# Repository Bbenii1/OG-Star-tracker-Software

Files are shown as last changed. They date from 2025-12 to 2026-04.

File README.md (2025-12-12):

<p align="center" style="height: 100px">
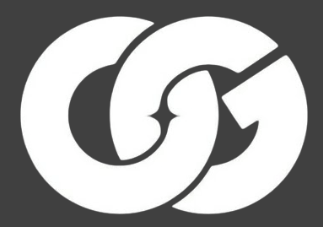
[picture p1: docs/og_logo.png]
  
</p>

> [!NOTE]  
> Fell free to try out my new hassle-free web based OG Star TrackerFirmware Flashing Tool by opening [this link](https://bbenii1.github.io/ogtracker-flash/).

# OG Star Tracker

OG Star Tracker is a mostly 3D printed star tracker which is cheaper than any competitor, but has the same features and can be controlled from it's self hosted web interface. It can be made as a diy project or you can [buy](https://ogstartech.com/shop/) it already assembled. The tracker can handle 400mm of focal length and up to 6kg of payload capacity if you upgrade to the heavy duty version. It is easily customizable and upgradable, for example you can add another axis to it, so you will be able to use it as a GO-TO tracker. The project is open source, therefore easy to make and contribute to. The project came true thanks to the founder [Ondrej Gejdos](https://github.com/OndraGejdos) and the amazing [community](https://discord.gg/Zj2jpAkn8b) that contributed to the project.

# What is this repository?

This is my restructured and simplified version of the [official repository](https://github.com/OG-star-tech/OG-star-tracker-). This repository only focuses on version 2 of the tracker, so if you would like to know more about version 1 of the tracker please go to the [official repository](https://github.com/OG-star-tech/OG-star-tracker-).

# How to build it?
There are a 3 options you can take when deciding how would you like to make the tracker.

### Preassembled kit
 If you like easy things and you don't want to fiddle with assembly then you can buy the [already assembled kit](https://ogstartech.com/product/og-star-tracker-v2-fully-build/) from the website.

### DIY kit
 You have the option to buy the [DIY kit](https://ogstartech.com/product/og-star-tracker-kit/) from the website with all of the parts included. You can easily assemble your tracker, the kit includes all of the parts that you will need. To your tracker assemble you can follow the included manual or the  [video guide](https://www.youtube.com/watch?v=8lNT1Yxl7aw).

### DIY on your own

You might have a 3D printer and you would like to print the parts for the tracker? Then do so! You can find the [3D files](https://www.printables.com/model/348574-og-star-tracker-v2) on Printables and download them from there. To assemble the tracker you will also need some additional parts. For those you can buy the [hardware kit](https://ogstartech.com/product/og-star-tracker-hw-kit/) that includes all the needed parts apart from the 3D printed ones, or you can buy them separately on your own using [the list of parts](ttps://docs.google.com/spreadsheets/d/1V04zjGSebJ5LQbSmzs-h86T6Z9E3HwVkMj2nuVYQzYs/edit?gid=0#gid=0) or the list below. To your tracker assemble you can follow the [video guide](https://www.youtube.com/watch?v=8lNT1Yxl7aw).

> [!WARNING]  
> If you buy the parts on your own separately, you will need the [V2 PCB](https://ogstartech.com/product/og-star-tracker-pcb-board/) to be able to use the tracker.

<details>
<summary>Parts for assembly</summary>

|Parts | Quantity |
|---|---|
| M3x6 socket bolt | 2 |
| M3x8 socket bolt | 40 |
| M3x16 socket bolt | 4 |
| M3x20 socket bolt | 8 |
| M3x40 socket bolt | 4 |
| M5x20 Low profile socket bolt  | 1 |
| M5x25 socket bolt | 1 |
| M5x50 Hex head | 2 |
| M5 ptfe washer | 1 |
| M3 threaded insert | 60 |
| M5 threaded insert | 5 |
| M3 nut | 3 |
| M5 nut | 3 |
| M5 self-tightening nuts | 2 |
| ¼-20x1/2” UNC Hex head | 2 |
| 3/8-16 threaded insert | 1 |
| ¼-20 UNC to 3/8-20 UNC adapter | 2 |
| AXK 5070 needle bearing | 2 |
| AS 5070 Axial bearing washer | 4 |
| KU 5025 sleeve bearing | 1 |
| 625 bearing | 10 |
| GT2 16 teeth pulley | 3 |
| GT2 48 teeth pulley | 2 |
| GT2 20 teeth idler | 1 |
| GT2 120mm belt | 2 |
| GT2 400mm belt | 1 |
| 5x50mm shaft | 2 |
| M5x95mm rod | 1 |
| M5x135mm rod | 1 |
| Round bubble level 12x7mm | 1 |
| PTFE based grease | 1 |
| Round magnet 10x3mm | 4 |
| Round magnet 5x5mm | 2 |
| Stepper motor | 1 |
| [PCB](https://ogstartech.com/product/og-star-tracker-pcb-board/) | 1 |

|Optional parts|
|-|
| Glue                           |     1    |
| Laser or polar scope           |
| 4mm hex key                    |
| 2.5mm hex key                  |
| 2mm hex key                    |
</details>

<br>

# Features
- Wirelessly Control the tracker from your phone/laptop by connecting to a webpage
- Supports AP (Access Point) and STA (Station) mode
 -- AP  : The ESP32 will create a wifi network which you can connect to
 -- STA : The ESP32 connects to an existing wifi network specified by you, Ex: phone hotspot. (Not fully tested)
- Integrated intervalometer which can control your camera shutter, no need to buy extra hardware. Exposures can be controlled via the webpage
  - Intervalometer Modes:
    - Long Exposure Still: Classic astro mode with tracking to get long exposures on the same target. Optional dithering.
    - Long Exposure Movie: Long exposures with tracking and dither plus at the end of a set of exposures the axis is rewound (a frame) and the next set started. This give the ability to create a movie          of the night sky moving over a terrestrial object when couple with a video making software.
    -  Day Time Lapse: Standard time lapse with exposure settings controlled by the camera.
    -  Day Time Lapse with Pan: Standard time lapse with exposure settings controlled by the camera plus a pan of X degrees in between every exposure.
- Presets : Up to 10 preset intervalometer settings can be saved for retrieval next session.
- Slewing supported at different speeds.

# Important links

Website - [ogstartech.com](https://ogstartech.com/) <br>
Discord - [Community](https://discord.gg/Zj2jpAkn8b) <br>
Printables - [printables.com](https://www.printables.com/model/348574-og-star-tracker-v2)

## License

This work is licensed under a
[Creative Commons Attribution-NonCommercial-ShareAlike 4.0 International License](http://creativecommons.org/licenses/by-nc-sa/4.0/)



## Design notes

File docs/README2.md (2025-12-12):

# OG Star Tracker : Wireless Control Hardware (Rev 2.0)

This simple PCB and firmware intends to make it easier to control the OG Star Tracker. If you have any suggestions/ideas about new features or would like to contribute, post in the OG star tracker [discord server](https://discord.com/invite/dyFKm79gKJ) or message me (Discord: jahh#8924).
If you like this work, feel free to connect with me on [Github](https://github.com/jugal2001) or [Linkedin](https://www.linkedin.com/in/jugaljesing/).

## Table of Contents
- [Compiling](compiling.md)
- [Wifi Config](wifi_config.md)

## Firmware

The firmware for the PCB is provided in this repository and can be compiled and flashed with the given [instructions](compiling.md).
Upon turning on the tracker will create an access point with the following default credentials that you can use to connect and control it:

```
SSID: OG Star Tracker
Password: password123
```

After a successful connection you can open **tracker.local** in your browser using your phone or desktop. The tracker hosts its own interface for convenient controlling.

You can set your own wifi configuration following [this tutorial](wifi_config.md).

[API](API.md)

## App

If the webserver is not enough there is a app available to improve the accessibility even further.
Check out https://github.com/OndraGejdos/OG-star-tracker-App for more details.

## Contributing

When contributing to the project please make sure to follow the [coding style](docs/coding-style.md) prior creating a pull request.
With this we can make sure to keep a clean and tidy codespace.

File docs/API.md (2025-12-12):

# OG Star Tracker REST API Documentation

## Overview
The OG Star Tracker provides a REST API over HTTP for remote control and monitoring. All endpoints use GET requests and return either plain text or JSON responses.

**Base URL:** `http://<device-ip>/`  
**Default Port:** 80

---

## Table of Contents
1. [Tracking Control](#tracking-control)
2. [Slewing Control](#slewing-control)
3. [Goto Control](#goto-control)
4. [Position Management](#position-management)
5. [Intervalometer Control](#intervalometer-control)
6. [Tracking Rates](#tracking-rates)
7. [Status & Info](#status--info)
8. [Catalog Search](#catalog-search)
9. [Settings](#settings)
10. [OTA Firmware Update](#ota-firmware-update)

---

## Tracking Control

### Enable Tracking
**Endpoint:** `GET /on`  
**Description:** Enable sidereal tracking at specified rate and direction

**Parameters:**
| Parameter | Type | Required | Description |
|---|---|---|---|
| `direction` | integer | Yes | Hemisphere/direction: 0=northern/clockwise, 1=southern/counter-clockwise |
| `trackingSpeed` | integer | Yes | Tracking rate value (depends on tracking rate type selected) |

**Response:** `200 OK` - "Tracking ON"

**Example:**
```
GET http://192.168.4.1/on?direction=0&trackingSpeed=15956
```

### Disable Tracking
**Endpoint:** `GET /off`  
**Description:** Disable sidereal tracking  
**Response:** `200 OK` - "Tracking OFF"

**Example:**
```
GET http://192.168.4.1/off
```

---

## Slewing Control

### Start Slewing
**Endpoint:** `GET /startslew`  
**Description:** Start manual slewing at specified speed  

**Parameters:**
| Parameter | Type | Required | Description |
|---|---|---|---|
| `speed` | integer | Yes | Slew speed multiplier (2-400, lower=faster) |
| `direction` | integer | Yes | Direction: 0=left/west, 1=right/east |

**Response:** `200 OK` - "Slewing"

**Example:**
```
GET http://192.168.4.1/startslew?speed=16&direction=1
```

### Stop Slewing
**Endpoint:** `GET /stopslew`  
**Description:** Stop current slewing operation  
**Response:** `200 OK` - "Slew Cancelled"

**Example:**
```
GET http://192.168.4.1/stopslew
```

---

## Goto Control

### Goto RA Position
**Endpoint:** `GET /gotoRA`  
**Description:** Move mount to target RA position  

**Parameters:**
| Parameter | Type | Required | Description |
|---|---|---|---|
| `currentRA` | string | Yes | Current RA position (HH:MM:SS format) |
| `targetRA` | string | Yes | Target RA position (HH:MM:SS format) |
| `speed` | integer | Yes | Goto speed multiplier (2-400, lower=faster) |

**Response:** `200 OK` - "Goto RA - Panning ON"

**Example:**
```
GET http://192.168.4.1/gotoRA?currentRA=12:30:45&targetRA=14:20:30&speed=8
```

### Abort Goto
**Endpoint:** `GET /abort-goto-ra`  
**Description:** Abort current goto RA operation  
**Response:** `200 OK` - "Goto RA aborted"

**Example:**
```
GET http://192.168.4.1/abort-goto-ra
```

---

## Position Management

### Set Position
**Endpoint:** `GET /setPosition`  
**Description:** Set current mount position  

**Parameters:**
| Parameter | Type | Required | Description |
|---|---|---|---|
| `currentRA` | string | Yes | Current RA position (HH:MM:SS format) |

**Response:** `200 OK` - "Position Set Success"

**Example:**
```
GET http://192.168.4.1/setPosition?currentRA=12:30:45
```

### Get Current Position
**Endpoint:** `GET /getCurrentPosition`  
**Description:** Get current mount position in steps  

**Response:** `200 OK` - JSON object
```json
{
  "position": 123456
}
```

**Example:**
```
GET http://192.168.4.1/getCurrentPosition
```

---

## Intervalometer Control

### Configure and Start Capture
**Endpoint:** `GET /setCurrent`  
**Description:** Configure and start intervalometer capture sequence  

**Parameters:**
| Parameter | Type | Required | Description |
|---|---|---|---|
| `mode` | integer | Yes | 0=start capture, 1=save to preset |
| `preset` | integer | Yes | Preset number (0-4) |
| `captureMode` | integer | Yes | 0=LONG_EXPOSURE_STILL, 1=LONG_EXPOSURE_MOVIE, 2=TIMELAPSE, 3=TIMELAPSE_PAN, |
| `exposureTime` | integer | Yes | Exposure duration in seconds |
| `exposures` | integer | Yes | Number of exposures |
| `preDelay` | integer | Yes | Pre-delay in seconds |
| `delay` | integer | Yes | Delay between exposures in seconds |
| `frames` | integer | Yes | Number of frames (for MOVIE mode) |
| `panAngle` | integer | Yes | Pan angle in degrees × 100 |
| `panDirection` | integer | Yes | 0=left/west, 1=right/east |
| `enableTracking` | integer | Yes | 0=off, 1=on |
| `ditherChoice` | integer | Yes | 0=off, 1=on |
| `ditherFrequency` | integer | Yes | Dither every N exposures |
| `focalLength` | integer | Yes | Focal length in mm |
| `pixelSize` | integer | Yes | Pixel size in microns × 100 |

**Response:** `200 OK` - Success message or error

**Example:**
```
GET http://192.168.4.1/setCurrent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
```

### Read Preset
**Endpoint:** `GET /readPreset`  
**Description:** Load intervalometer preset settings  

**Parameters:**
| Parameter | Type | Required | Description |
|---|---|---|---|
| `preset` | integer | Yes | Preset number (0-4) |

**Response:** `200 OK` - JSON object with preset settings
```json
{
  "mode": 0,
  "exposures": 10,
  "delay": 2,
  "preDelay": 5,
  "exposureTime": 30,
  "panAngle": 0,
  "panDirection": 1,
  "ditherChoice": 1,
  "ditherFrequency": 3,
  "enableTracking": 1,
  "frames": 1,
  "pixelSize": 350,
  "focalLength": 200
}
```

**Example:**
```
GET http://192.168.4.1/readPreset?preset=0
```

### Abort Capture
**Endpoint:** `GET /abort`  
**Description:** Abort current intervalometer capture sequence  
**Response:** `200 OK` - "Capture OFF"

**Example:**
```
GET http://192.168.4.1/abort
```

---

## Tracking Rates

### Get Tracking Rates
**Endpoint:** `GET /getTrackingRates`  
**Description:** Get current tracking rate configuration  

**Response:** `200 OK` - JSON object
```json
{
  "type": 0,
  "customRate": 0
}
```
**Types:** 0=SIDEREAL, 1=LUNAR, 2=SOLAR, 3=CUSTOM

**Example:**
```
GET http://192.168.4.1/getTrackingRates
```

### Save Tracking Rate Preset
**Endpoint:** `GET /saveTrackingRatePreset`  
**Description:** Save tracking rate to preset  

**Parameters:**
| Parameter | Type | Required | Description |
|---|---|---|---|
| `preset` | integer | Yes | Preset number (0-4) |
| `type` | integer | Yes | 0=SIDEREAL, 1=LUNAR, 2=SOLAR, 3=CUSTOM |
| `customRate` | integer | No | Custom rate value (required if type=3) |

**Response:** `200 OK` - Success message

**Example:**
```
GET http://192.168.4.1/saveTrackingRatePreset?preset=0&type=0&customRate=0
```

### Load Tracking Rate Preset
**Endpoint:** `GET /loadTrackingRatePreset`  
**Description:** Load tracking rate from preset  

**Parameters:**
| Parameter | Type | Required | Description |
|---|---|---|---|
| `preset` | integer | Yes | Preset number (0-4) |

**Response:** `200 OK` - JSON object with tracking rate settings

**Example:**
```
GET http://192.168.4.1/loadTrackingRatePreset?preset=0
```

---

## Status & Info

### Get Status
**Endpoint:** `GET /status`  
**Description:** Get device status information  

**Response:** `200 OK` - JSON object
```json
{
  "slewActive": false,
  "trackingActive": true,
  "intervalometerActive": false,
  "goToTarget": false,
  "exposuresTaken": 0,
  "currentExposure": 0
}
```

**Example:**
```
GET http://192.168.4.1/status
```

### Get Version
**Endpoint:** `GET /version`  
**Description:** Get firmware version and build information  

**Response:** `200 OK` - JSON object
```json
{
  "version": "v2.1",
  "buildDate": "Nov 22 2025 10:30:00",
  "internalVersion": 210
}
```

**Response Fields:**
| Field | Type | Description |
|---|---|---|
| `version` | string | Firmware version string (from BUILD_VERSION define) |
| `buildDate` | string | Compilation date and time |
| `internalVersion` | integer | Internal version number for comparison |

**Example:**
```
GET http://192.168.4.1/version
```

**Notes:**
- `buildDate` format: "MMM DD YYYY HH:MM:SS" (e.g., "Nov 22 2025 10:30:00")
- `internalVersion` is a numeric value for programmatic version comparison
- Same data returned by `/checkversion` endpoint in OTA section

---

## Catalog Search

### Search Star/Object Catalog
**Endpoint:** `GET /starSearch`  
**Description:** Search star/object catalog by name  

**Parameters:**
| Parameter | Type | Required | Description |
|---|---|---|---|
| `catalog` | integer | Yes | 0=NGC2000, 1=NGC2000_COMPACT, 2=BSC5, 3=BSC5_COMPACT |
| `query` | string | Yes | Search query string (star/object name) |

**Response:** `200 OK` - JSON object with search results

**Example:**
```
GET http://192.168.4.1/starSearch?catalog=0&query=M31
```

---

## Settings

### Set Language
**Endpoint:** `GET /setlang`  
**Description:** Set web interface language  

**Parameters:**
| Parameter | Type | Required | Description |
|---|---|---|---|
| `lang` | integer | Yes | 0=English, 1=German, 2=Chinese |

**Response:** `200 OK` - Success message

**Example:**
```
GET http://192.168.4.1/setlang?lang=0
```

### Get Current Language
**Endpoint:** `GET /getlang`
**Description:** Get currently selected language index

**Response:** `200 OK` - JSON object
```json
{
  "lang": 0
}
```

**Example:**
```
GET http://192.168.4.1/getlang
```

### Get Language Strings
**Endpoint:** `GET /langstrings`
**Description:** Get all translated strings for current language as JSON

**Response:** `200 OK` - JSON object with language strings and language names
```json
{
  "strings": {
    "%STR_TRACKING%": "Tracking",
    "%STR_SLEWING%": "Slewing",
    ...
  },
  "langNames": ["English", "Deutsch", "中文"]
}
```

**Example:**
```
GET http://192.168.4.1/langstrings
```

**Notes:**
- Response is streamed using chunked encoding to reduce memory usage
- Contains all UI string placeholders and their translations
- Language names array used for building language selector dropdown

### Get Web Interface
**Endpoint:** `GET /`  
**Description:** Serve main web interface HTML  

**Response:** `200 OK` - HTML content

**Example:**
```
GET http://192.168.4.1/
```

---

## OTA Firmware Update

### Get OTA Update Page
**Endpoint:** `GET /ota`  
**Description:** Serve OTA firmware update web interface  

**Response:** `200 OK` - HTML content with firmware update interface

**Example:**
```
GET http://192.168.4.1/ota
```

---

### Check for Updates
**Endpoint:** `GET /checkversion`  
**Description:** Check GitHub for latest firmware release and compare with current version  

**Response:** `200 OK` - JSON object
```json
{
  "currentVersion": "v2.1",
  "buildDate": "Nov 22 2025 10:30:00",
  "latestVersion": "v2.1-beta03",
  "releaseUrl": "https://github.com/OG-star-tech/OG-star-tracker-/releases/tag/v2.1-beta03",
  "downloadUrl": "https://github.com/OG-star-tech/OG-star-tracker-/releases/download/v2.1-beta03/firmware.bin",
  "releaseNotes": "Bug fixes|Performance improvements|New features"
}
```

**Error Response:**
```json
{
  "currentVersion": "v2.1",
  "buildDate": "Nov 22 2025 10:30:00",
  "error": "No internet connection. If in AP mode, connect device to WiFi network with internet access."
}
```

**Example:**
```
GET http://192.168.4.1/checkversion
```

**Notes:**
- **Requires internet access:** Device must be connected to a WiFi network with internet access (not AP mode)
- **AP Mode Limitation:** When device is in Access Point mode, it cannot reach GitHub API. Connect the device to a WiFi network with internet access first
- Release notes are pipe-separated (|) for multi-line display
- Returns latest release even if same or older than current version

---

### Download and Install Update
**Endpoint:** `GET /downloadupdate`  
**Description:** Download firmware from URL and install automatically (GitHub release or custom URL)  

**Parameters:**
| Parameter | Type | Required | Description |
|---|---|---|---|
| `url` | string | Yes | Direct URL to firmware.bin file (URL-encoded) |

**Response:** `200 OK` - "Starting download..."

**Example:**
```
GET http://192.168.4.1/downloadupdate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
```

**Process Flow:**
1. Server validates URL parameter and WiFi connection
2. Returns immediate response "Starting download..."
3. Downloads firmware in background (512-byte chunks)
4. Writes to flash partition with verification
5. Device reboots automatically after 6 seconds if successful

**Error Responses:**
- `400 Bad Request` - "Missing URL parameter"
- `500 Internal Server Error` - "WiFi not connected"

**Notes:**
- **Requires internet access:** Device must be connected to a WiFi network with internet access (not AP mode)
- Use `/otastatus` endpoint to monitor download progress
- Device stays responsive during download (polls every 500ms)
- Typical download time: 30-60 seconds for ~1.2MB firmware
- URL must point directly to `.bin` file

---

### Manual Firmware Upload
**Endpoint:** `POST /update`  
**Description:** Upload firmware binary file directly via HTTP POST (multipart/form-data)  

**Content-Type:** `multipart/form-data`

**Form Field:**
| Field | Type | Description |
|---|---|---|
| `firmware` | file | Binary firmware file (.bin format) |

**Response:** `200 OK` - "Update Success! Rebooting..." or "Update Failed"

**Example (curl):**
```bash
curl -X POST -F "firmware=@firmware.bin" http://192.168.4.1/update
```

**Process Flow:**
1. Receives firmware chunks via multipart upload
2. Writes directly to flash partition during upload
3. Verifies integrity after upload completes
4. Device reboots automatically after 6 seconds if successful

**Notes:**
- Maximum file size: Limited by available flash partition (~2MB typical)
- Upload progress reported via `/otastatus` endpoint
- Use `/complete` endpoint to trigger reboot after upload verification

---

### Get OTA Status
**Endpoint:** `GET /otastatus`  
**Description:** Get real-time status of ongoing OTA update (upload or download)  

**Response:** `200 OK` - JSON object
```json
{
  "active": true,
  "complete": false,
  "error": false,
  "bytesWritten": 524288,
  "totalBytes": 1244160,
  "percent": 42
}
```

**Status Fields:**
| Field | Type | Description |
|---|---|---|
| `active` | boolean | Update is actively downloading/uploading |
| `complete` | boolean | Update completed successfully, ready to reboot |
| `error` | boolean | Update failed (check serial output for details) |
| `bytesWritten` | integer | Bytes written to flash so far |
| `totalBytes` | integer | Total firmware size in bytes |
| `percent` | integer | Progress percentage (0-100) |

**Example:**
```
GET http://192.168.4.1/otastatus
```

**Polling Pattern:**
```javascript
// Poll every 500ms during update
const interval = setInterval(async () => {
  const response = await fetch('/otastatus');
  const data = await response.json();
  
  if (data.active) {
    console.log(`Progress: ${data.percent}%`);
  } else if (data.complete) {
    console.log('Update complete, device rebooting...');
    clearInterval(interval);
  } else if (data.error) {
    console.log('Update failed');
    clearInterval(interval);
  }
}, 500);
```

**Notes:**
- Poll during `/downloadupdate` or `/update` operations
- `active=false, complete=false, error=false` at 100% indicates verification phase
- Verification timeout: 5 seconds (frontend should show error after timeout)

---

### Complete OTA Update
**Endpoint:** `GET /complete`  
**Description:** Finalize OTA update and trigger device reboot (called automatically by frontend)  

**Response:** `200 OK` - "Update Success! Rebooting..." or "Update Failed"

**Example:**
```
GET http://192.168.4.1/complete
```

**Notes:**
- Checks for errors before rebooting
- 6-second delay before reboot (server stays responsive)
- Typically called automatically by OTA web interface
- Returns error status if update verification failed

---

### OTA Update Workflow

**Automatic Update (GitHub):**
```
1. GET /checkversion                    -> Get latest release info
2. User confirms update
3. GET /downloadupdate?url=<firmware>   -> Start download
4. Poll GET /otastatus every 500ms      -> Monitor progress (0-100%)
5. Verification phase (2-5 seconds)     -> active=false, complete waiting
6. GET /complete called automatically   -> Trigger reboot
7. Device reboots after 6 seconds
```

**Manual Upload:**
```
1. User selects .bin file
2. POST /update with multipart form     -> Upload begins
3. Poll GET /otastatus every 500ms      -> Monitor progress (0-100%)
4. Verification phase (2-5 seconds)     -> active=false, complete waiting
5. GET /complete called automatically   -> Trigger reboot
6. Device reboots after 6 seconds
```

**Error Handling:**
- Flash read failures detected during verification
- Timeout if verification exceeds 5 seconds
- Write errors reported immediately via `/otastatus` (error=true)
- Serial output provides detailed error messages

**Safety Features:**
- Server remains responsive during entire process (non-blocking delays)
- Progress tracking prevents UI from hanging
- Automatic rollback on write failures
- 6-second countdown gives user time to see status

---

## Error Responses

All endpoints may return error messages in plain text format with appropriate HTTP status codes:

- `400 Bad Request` - Invalid parameters
- `404 Not Found` - Endpoint not found
- `500 Internal Server Error` - Server error

---

## Notes

1. **RA Format:** All RA positions use HH:MM:SS format (e.g., "12:30:45")
2. **Scaled Values:** Some values are scaled by 100 (panAngle, pixelSize) to avoid floating point in URL parameters
3. **Direction Convention:** 0=left/west, 1=right/east for all directional parameters
4. **Speed Convention:** Lower speed values = faster movement (range: 2-400)
5. **Preset Numbering:** All presets are numbered 0-4 (5 presets total)

---

## Example Usage

### Python Example
```python
import requests

# Base URL of your star tracker
base_url = "http://192.168.4.1"

# Enable tracking
response = requests.get(f"{base_url}/on")
print(response.text)

# Start a 30-second exposure timelapse with 10 exposures
params = {
    "mode": 0,
    "preset": 0,
    "captureMode": 0,
    "exposureTime": 30,
    "exposures": 10,
    "preDelay": 5,
    "delay": 2,
    "frames": 1,
    "panAngle": 0,
    "panDirection": 1,
    "enableTracking": 1,
    "ditherChoice": 0,
    "ditherFrequency": 1,
    "focalLength": 200,
    "pixelSize": 350
}
response = requests.get(f"{base_url}/setCurrent", params=params)
print(response.text)

# Check status
response = requests.get(f"{base_url}/status")
print(response.json())
```

### JavaScript Example
```javascript
const baseUrl = "http://192.168.4.1";

// Enable tracking
fetch(`${baseUrl}/on`)
  .then(response => response.text())
  .then(data => console.log(data));

// Get status
fetch(`${baseUrl}/status`)
  .then(response => response.json())
  .then(data => console.log(data));

// Start slewing
fetch(`${baseUrl}/startslew?speed=16&direction=1`)
  .then(response => response.text())
  .then(data => console.log(data));
```

---

## Version History

- **v2.1.0-beta03** - Initial REST API documentation
  - Added TIMELAPSE_PAN mode
  - Improved position tracking
  - Enhanced error handling
  - Added OTA firmware update endpoints
  - Real-time update progress tracking
  - Automatic and manual update support

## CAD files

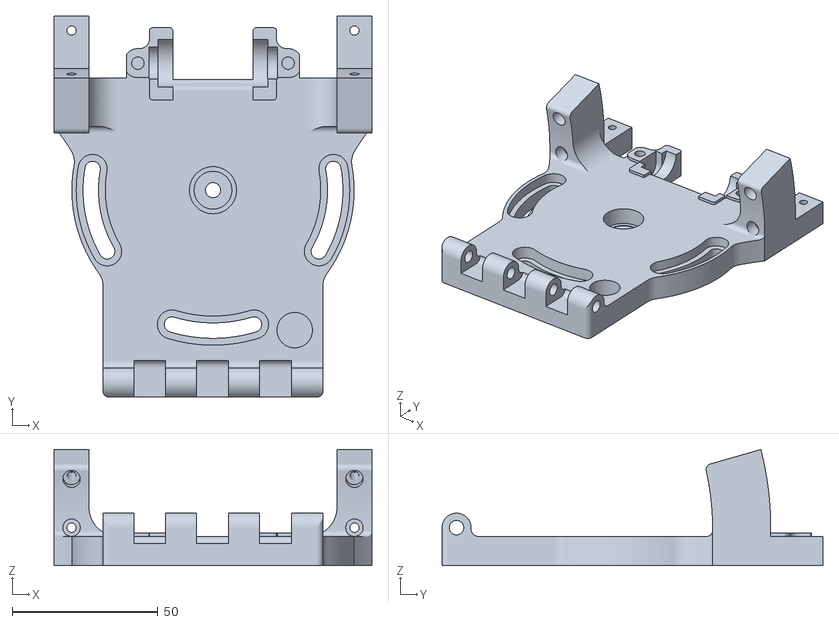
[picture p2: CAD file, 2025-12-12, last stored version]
mechanics/Heavy duty/main-bottom-part-hd.stl
109.2 x 130.9 x 39.9

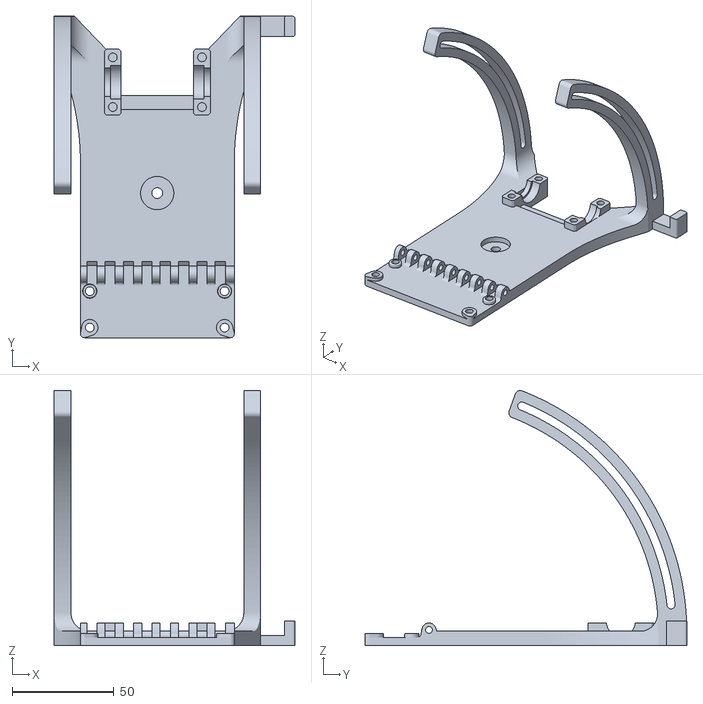
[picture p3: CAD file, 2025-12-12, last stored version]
v1/mechanics/bottom asembly/bottom main part.stl
118.2 x 157.9 x 125.2

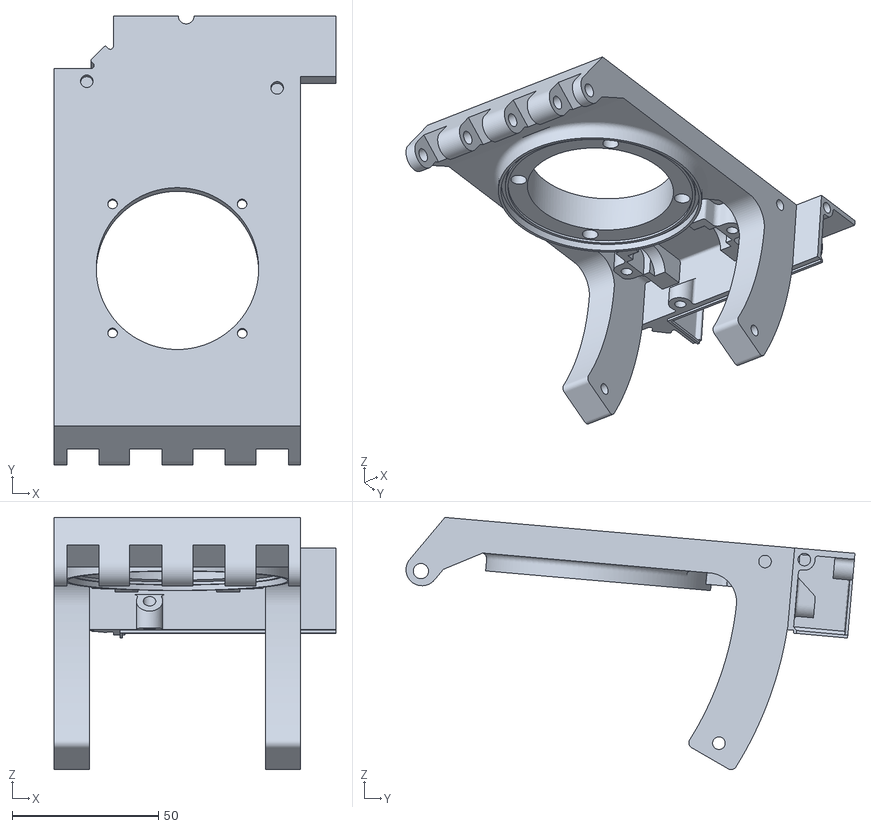
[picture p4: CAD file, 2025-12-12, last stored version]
mechanics/Heavy duty/main-top-part-hd.stl
96.2 x 153.4 x 86.2

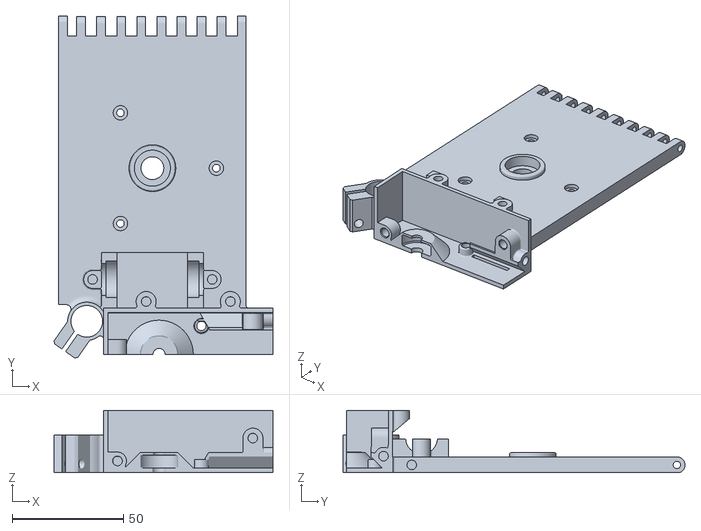
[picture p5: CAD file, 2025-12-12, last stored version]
v1/mechanics/top asembly/main part.stl
98.2 x 153.5 x 28.0

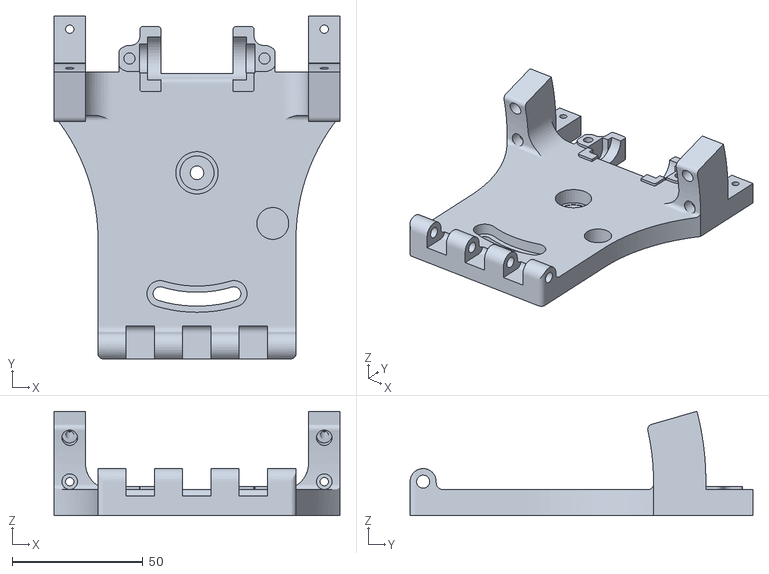
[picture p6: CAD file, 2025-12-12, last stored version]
mechanics/V2 files/main-bottom-part.stl
109.2 x 130.9 x 39.9

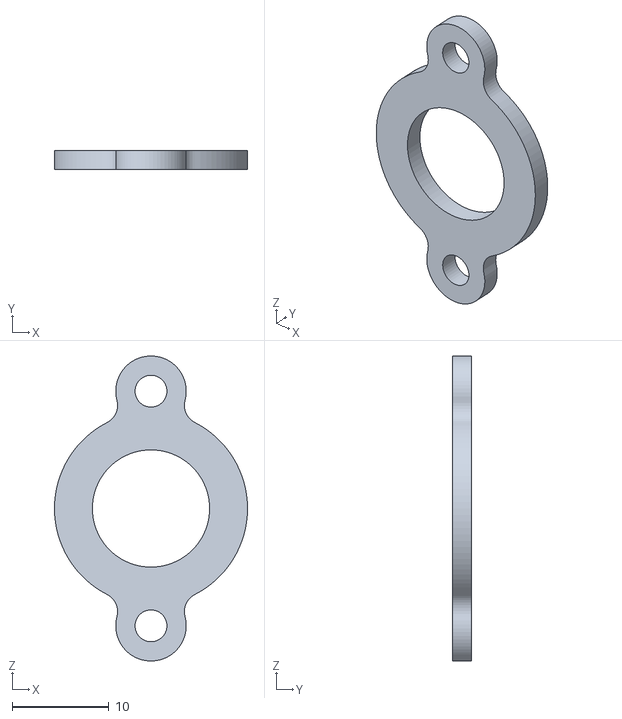
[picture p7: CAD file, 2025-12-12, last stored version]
mechanics/V2 files/main-gearbox-bearing-holderstl.stl
20.0 x 2.00 x 31.6

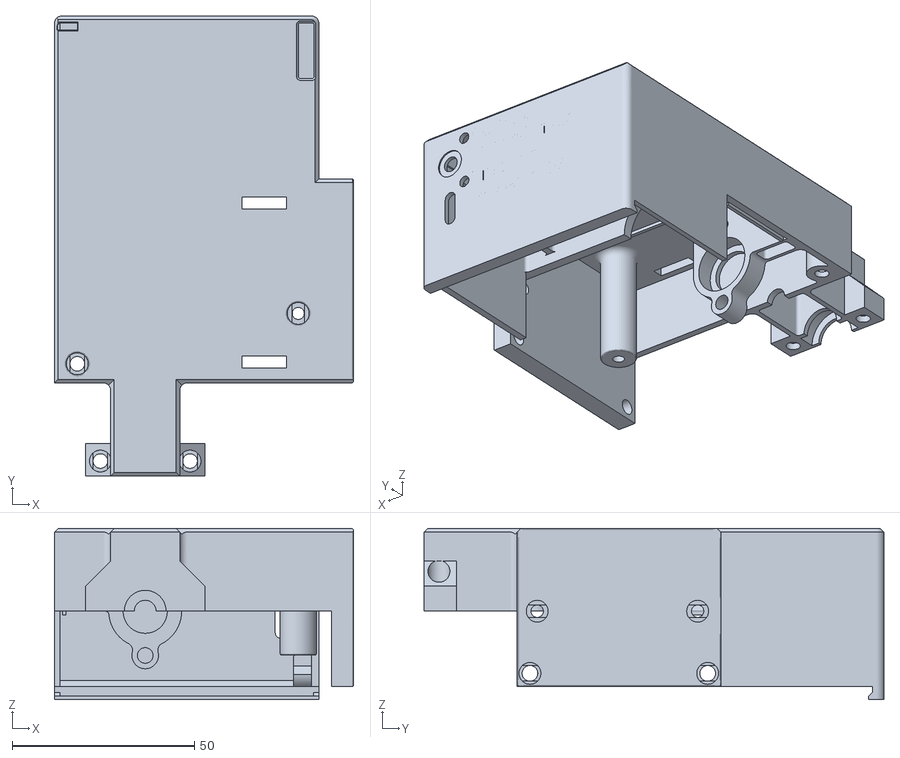
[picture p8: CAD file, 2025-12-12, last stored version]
mechanics/V2 files/main-gearbox.stl
82.0 x 126.2 x 47.0

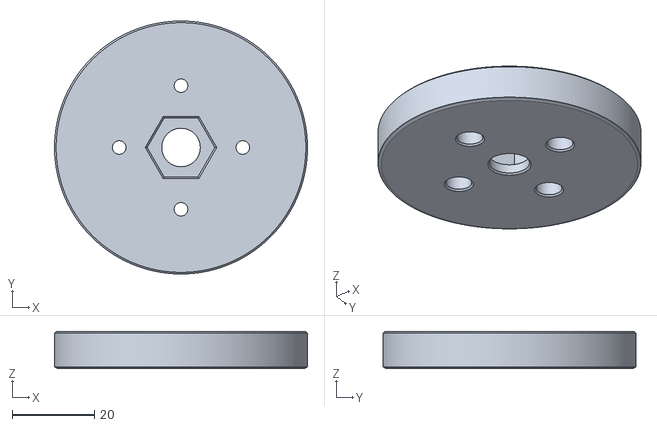
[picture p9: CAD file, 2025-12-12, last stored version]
community_upgrades/beefier_gearbox_multicolor/stls/camera-holder-3-8-16-x-1-2.stl
61.4 x 61.4 x 9.00

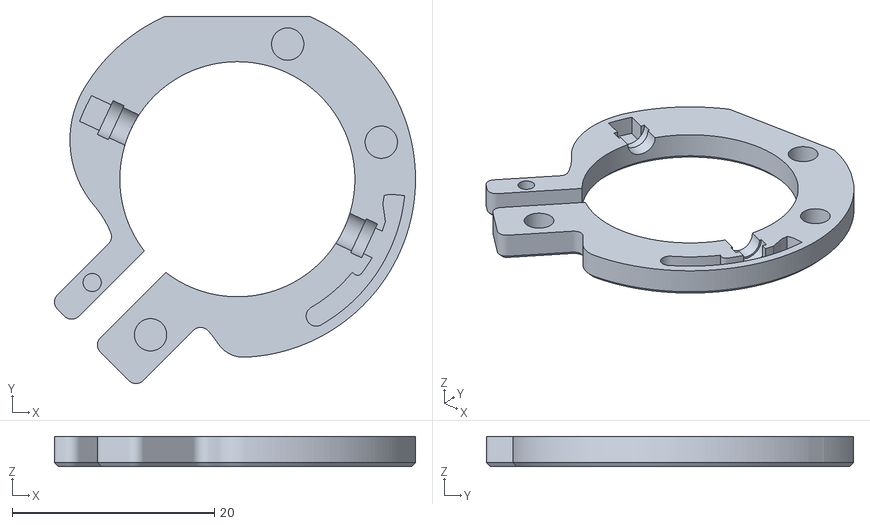
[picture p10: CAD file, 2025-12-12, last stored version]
community_upgrades/illuminated_polarscope/stls/led-top-cap.stl
35.7 x 36.3 x 3.00

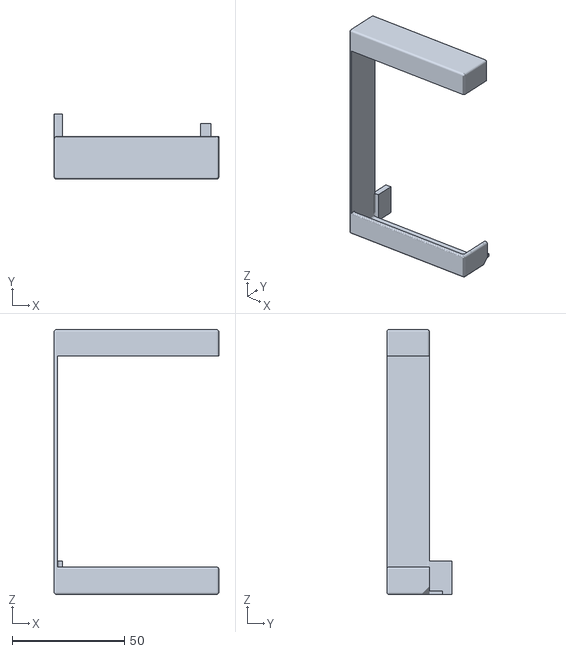
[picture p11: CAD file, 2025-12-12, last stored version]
community_upgrades/power_bank_holder/OGstartracker ONN battery mount.stl
73.4 x 29.2 x 118.2

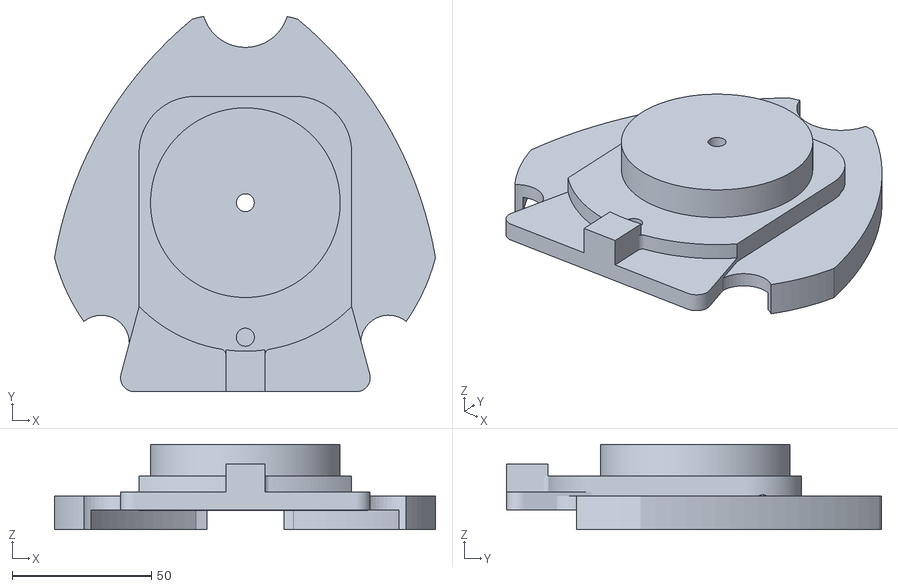
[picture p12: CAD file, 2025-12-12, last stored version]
community_upgrades/surveyor_tripod_adapter/stationary_part_with_surveyor_adapter2.stl
136.6 x 134.6 x 30.6

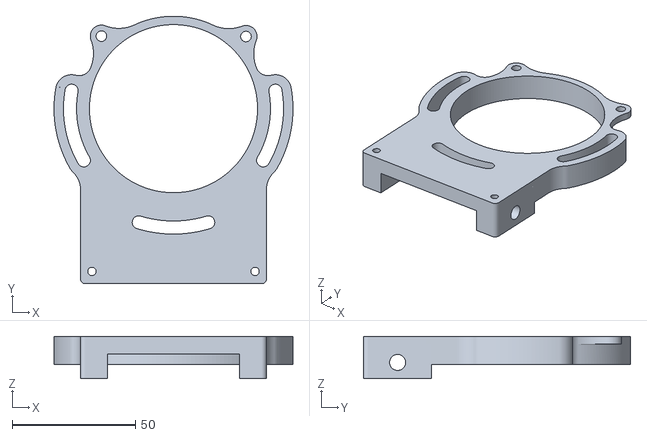
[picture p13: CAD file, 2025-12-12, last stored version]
mechanics/Heavy duty/middle-part-hd.stl
97.0 x 108.6 x 17.1

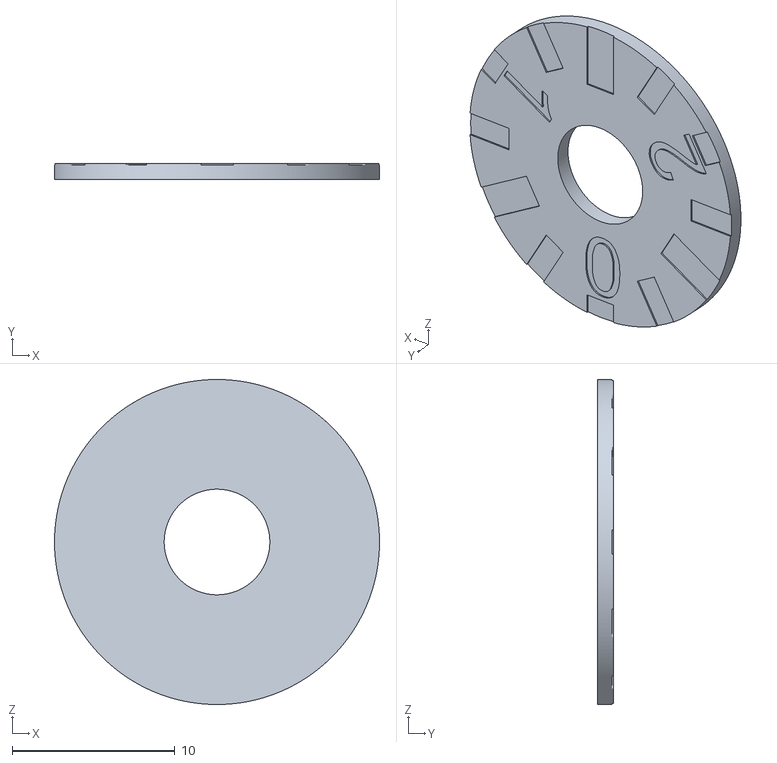
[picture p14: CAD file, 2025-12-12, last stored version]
mechanics/Manual go-to beta testing/small-scale-2.stl
20.0 x 1.00 x 20.0

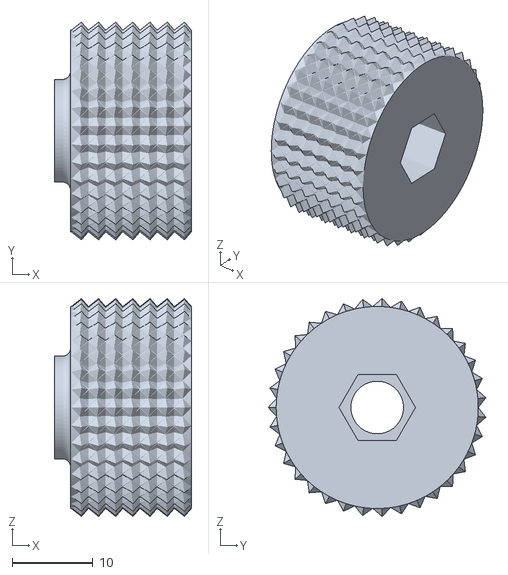
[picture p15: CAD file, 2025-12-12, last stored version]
mechanics/V2 files/m5-knob.stl
17.0 x 26.9 x 27.0

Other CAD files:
mechanics/V2 files/main-top-part.stl
v1/mechanics/electronic box/top cover.stl
v1/mechanics/top asembly/tightener 2x.stl
v1/mechanics/you also need to print this/bottom holder 2x!.stl
community_upgrades/beefier_gearbox_multicolor/stls/belt-cover-modded-needs_supports.stl
community_upgrades/beefier_gearbox_multicolor/stls/belt-tightener-625-bearing-m5x16mm.stl
community_upgrades/beefier_gearbox_multicolor/stls/belt-tightener-f695-bearing-m5x16mm.stl
community_upgrades/beefier_gearbox_multicolor/stls/doors-modded-with-logo.stl
community_upgrades/beefier_gearbox_multicolor/stls/gearbox-part-1-2-combined-embossed_letters-v11.stl
community_upgrades/beefier_gearbox_multicolor/stls/gearbox-part-1-2-combined-with-multicolor-letters-v11.stl
community_upgrades/beefier_gearbox_multicolor/stls/gearbox-part-3-modded.stl
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

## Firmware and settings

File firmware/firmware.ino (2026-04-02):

#include <ArduinoJson.h>
#include <ESPmDNS.h>
#include <ErriezSerialTerminal.h>
#include <WebServer.h>
#include <WiFi.h>
#include <esp_wifi.h>
#include <freertos/FreeRTOS.h>
#include <string.h>

#include "axis.h"
#include "commands.h"
#include "common_strings.h"
#include "config.h"
#include "hardwaretimer.h"
#include "intervalometer.h"
#include "uart.h"
#include "i18n/web_languages.h"
#include "web/web_handlers.h"

SerialTerminal term(CLI_NEWLINE_CHAR, CLI_DELIMITER_CHAR);
WebServer server(WEBSERVER_PORT);
Languages language = EN;

void uartTask(void* pvParameters);
void consoleTask(void* pvParameters);
void webserverTask(void* pvParameters);
void intervalometerTask(void* pvParameters);


void setup()
{
    // Start the debug serial connection
    setup_uart(&Serial, 115200);

    // start UART task before any usage of print_out
    if (xTaskCreate(uartTask, "uart", 4096, NULL, 1, NULL))
    {
        print_out_tbl(TSK_CLEAR_SCREEN);
        print_out_tbl(TSK_START_UART);
    }

    print_out_tbl(HEAD_LINE);
    print_out_tbl(HEAD_LINE_TRACKER);
    print_out("***         Running on %d MHz         ***", getCpuFrequencyMhz());
    print_out_tbl(HEAD_LINE_VERSION);

    EEPROM.begin(512); // SIZE = 5 x presets = 5 x 32 bytes = 160 bytes
    uint8_t langNum = EEPROM.read(LANG_EEPROM_ADDR);

    if (langNum >= LANG_COUNT)
        language = static_cast<Languages>(0);
    else
        language = static_cast<Languages>(langNum);

    // Initialize the pins
    pinMode(INTERV_PIN, OUTPUT);
    pinMode(STATUS_LED, OUTPUT);
    pinMode(AXIS1_STEP, OUTPUT);
    pinMode(AXIS1_DIR, OUTPUT);
    pinMode(EN12_n, OUTPUT);
    digitalWrite(AXIS1_STEP, LOW);
    digitalWrite(EN12_n, LOW);

    // Initialize Wifi and web server
    setupWireless();

    // Initialize the console serial
    setup_terminal(&term);

    if (xTaskCreate(consoleTask, "console", 4096, NULL, 1, NULL))
        print_out_tbl(TSK_START_CONSOLE);

    if (xTaskCreate(intervalometerTask, "intervalometer", 4096, NULL, 1, NULL))
        print_out_tbl(TSK_START_INTERVALOMETER);
    if (xTaskCreatePinnedToCore(webserverTask, "webserver", 4096, NULL, 1, NULL, 0))
        print_out_tbl(TSK_START_WEBSERVER);

    ra_axis.begin();
}

void loop()
{
    int delay_ticks = 0;

    if (DEFAULT_ENABLE_TRACKING == 1)
    {
        ra_axis.startTracking(ra_axis.rate.tracking, ra_axis.direction.tracking);
    }

    for (;;)
    {
        if (ra_axis.slewActive)
        {
            // Blink status LED if mount is in slew mode
            digitalWrite(STATUS_LED, !digitalRead(STATUS_LED));
            delay_ticks = 150; // Delay for 150 ms
        }
        else
        {
            // Turn on status LED if sidereal tracking is ON
            digitalWrite(STATUS_LED, ra_axis.trackingActive ? HIGH : LOW);
            delay_ticks = 1000; // Delay for 1 second
        }
        vTaskDelay(delay_ticks);
    }
}

void webserverTask(void* pvParameters)
{
    for (;;)
    {
        server.handleClient();
        vTaskDelay(1);
    }
}

void intervalometerTask(void* pvParameters)
{
    intervalometer.readPresetsFromEEPROM();

    for (;;)
    {
        if (intervalometer.intervalometerActive)
            intervalometer.run();
        vTaskDelay(1);
    }
}

void uartTask(void* pvParameters)
{
    for (;;)
    {
        uart_task();
        vTaskDelay(1);
    }
}

void consoleTask(void* pvParameters)
{
    for (;;)
    {
        term.readSerial();
        vTaskDelay(1);
    }
}

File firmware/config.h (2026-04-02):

#ifndef CONFIG
#define CONFIG 1

#ifdef HAVE_WIFI_CONFIG
#include "wifi_config.h"
#endif

#include "pins_config.h"

#define STEPPER_0_9 0 // 0.9 degree stepper motor
#define STEPPER_1_8 1 // 1.8 degree stepper motor

#define TRACKING_RATE_BOARD_V2 1

#define MOTOR_TRACKING_RATE TRACKING_RATE_BOARD_V2

/*To build in Arduino IDE, install esp32 boards V3.0x and the Arduinojson library by Benoit
 * Blanchon*/
/*****USER DEFINED*****/
// AP mode by default: ESP32 will create a wifi network which you can connect to
#ifndef c_DIRECTION
#define c_DIRECTION                // 1 is for north hemisphere and 0 for south hemisphere
#endif
#define RA_INVERT_DIR_PIN 1          // if need to invert direction pin set to 1
#define DEC_INVERT_DIR_PIN 0         // if need to invert direction pin set to 1
#define DEFAULT_ENABLE_TRACKING 1    // set to 1 to enable tracking at startup
#define DITHER_DISTANCE_X10_PIXELS 5 // set max distance to dither in multiple of 10 pixels
#define MAX_CUSTOM_SLEW_RATE 400     // Set max custom slew rate to X tracking rate
#define MIN_CUSTOM_SLEW_RATE 2       // Set min custom slew rate to X tracking rate

#ifndef TRACKING_RATE
// Available tracking rates:
// TRACKING_SIDEREAL
// TRACKING_SOLAR
// TRACKING_LUNAR
#define TRACKING_RATE TRACKING_SIDEREAL // default tracking rate
#endif

// Configure the stepper motor type
#ifndef STEPPER_TYPE
#define STEPPER_TYPE STEPPER_0_9 // 0.9 degree stepper motor
#endif
// Configure the wifi settings if you are not using platformio
#ifndef WIFI_SSID
#define WIFI_SSID "" // change to your SSID
#endif
#ifndef WIFI_PASSWORD
#define WIFI_PASSWORD "" // change to your password, must be 8+ characters
#endif
// If you are using AP mode, you can access the website using the below URL
#ifndef MDNS_NAME
#define MDNS_NAME "tracker"
#endif
#ifndef WEBSERVER_PORT
#define WEBSERVER_PORT 80
#endif

#ifndef INTERNAL_VERSION
#define INTERNAL_VERSION 7
#endif
/**********************/

#define TMC_R_SENSE 0.11f // Match to your driver
#define AXIS_SERIAL_PORT Serial2
#define AXIS_RX X_STOP
#define AXIS_TX Z_DIR

#define AXIS1_ADDR 0
#define AXIS2_ADDR 1

/**********************/

#define USE_MSx_PINS_MICROSTEPPING 1
#define USE_TMC_DRIVER_MICROSTEPPING 2

#define MICROSTEPPING_MOTOR_DRIVER USE_MSx_PINS_MICROSTEPPING

/*****DO NOT MODIFY BELOW*****/
// Set the resolution per step for the stepper motor
#if STEPPER_TYPE == STEPPER_0_9
#define ARCSEC_PER_STEP 2.0
#else
#define ARCSEC_PER_STEP 4.0
#endif

// LEDs for intervalometer status and general purpose status led
#define INTERV_PIN 25
#define STATUS_LED 26 // (Red)
#define LANG_EEPROM_ADDR 0
#define PRESETS_EEPROM_START_LOCATION 1

// WiFi credentials EEPROM layout (after presets: 1 + 10*28 = 281)
#define WIFI_EEPROM_MARKER_ADDR 281    // 2 bytes: magic marker 0xAB, 0xCD
#define WIFI_SSID_EEPROM_ADDR 283      // 32 bytes: null-terminated SSID
#define WIFI_PASSWORD_EEPROM_ADDR 315  // 64 bytes: null-terminated password
#define WIFI_SSID_MAX_LEN 32
#define WIFI_PASSWORD_MAX_LEN 64

// Stepper driver pins -- intended for TMC2209 for now
// AXIS 1 - RA
#define AXIS1_STEP 5
#define AXIS1_DIR 15
#define SPREAD_1 4
// AXIS 2 - DEC
#define AXIS2_STEP 19
#define AXIS2_DIR 18
#define SPREAD_2 21
// common pins
#define RA_MS1 23
#define RA_MS2 22
#define EN12_n 17

#endif

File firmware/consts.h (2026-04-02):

#ifndef _CONSTS_H_
#define _CONSTS_H_

#include "config.h"

#define SIDERAL_DAY_MS 86164000UL
#define SOLAR_DAY_MS 86400000UL
#define LUNAR_DAY_MS 88253300UL

#define MAX_MICROSTEPS 256UL

#define GEAR_RATIO 101.25

#if STEPPER_TYPE == STEPPER_0_9
#define STEPPER_STEPS_PER_REV 400 // 360 / 0.9
#else
#define STEPPER_STEPS_PER_REV 200 // 360 / 1.8
#endif

#define STEPS_PER_TRACKER_FULL_REV (STEPPER_STEPS_PER_REV * GEAR_RATIO * MAX_MICROSTEPS)

#endif /* _CONSTS_H_ */

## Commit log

2025-12-12 initial commit
    uploaded original files from https://github.com/Sylensky/OG-star-tracker-/tree/beta
    [OG star tracker part list.xlsx, OGstartracker ONN battery mount.stl, Parts for V2.ods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]
2025-12-12 full overhaul
    -updated readme
    -reconsidered file structure
    -deleted v1 files
    [OG star tracker part list.xlsx, OGstartracker ONN battery mount.stl, Parts for V2.ods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]
2025-12-12 Revise warning for assembly in README
2026-04-02 v2.2
    -wifi credentials change on the tracker's control panel; -removed unused variables and functions; -scripts for easier firmware building and versioning; -build parameters for both 0.9 and 1.8 stepper 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
